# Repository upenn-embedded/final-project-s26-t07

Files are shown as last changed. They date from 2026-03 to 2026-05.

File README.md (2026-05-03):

# RoboBartender

**Team Number:** 7

**Team Name:** Team 7

|  Team Member Name  | Email Address |
|---|---|
| Lori Brown | blor@seas |
| Amy Luo | amyluo@seas |
| Jeremy Chung | ddchung@seas |

**GitHub Repository URL:** https://github.com/upenn-embedded/final-project-s26-t07

**GitHub Pages Website URL:** https://upenn-embedded.github.io/final-project-s26-t07/

## Final Project Proposal

### 1. Abstract  
We are building an autonomous assembly-line mocktail mixer which allows users to select a drink option. We plan to use an OLED screen and buttons for drink selection and notifications. Solenoids and pumps used in conjunction with load cells for each bottle will dispense the liquid and notify the user if a bottle needs to be refilled. The cup (detected using a load cell) will move through a series of stages corresponding to each bottle.

### 2. Motivation  
Mocktail and tea prices have been going up in the past few years. It is no longer appealing to buy an 8 dollar peach oolong tea, for example, which is very easy to make. We propose an autonomous drink-maker to solve this problem and save ourselves money. We want a device that we can use at home with minimal maintenance and cost.

### 3. System Block Diagram
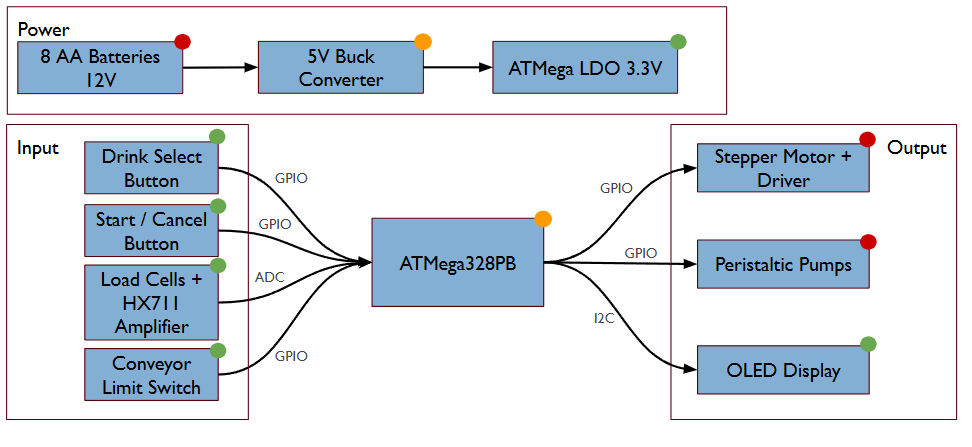
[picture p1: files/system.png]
   
### 4. Design Sketches  
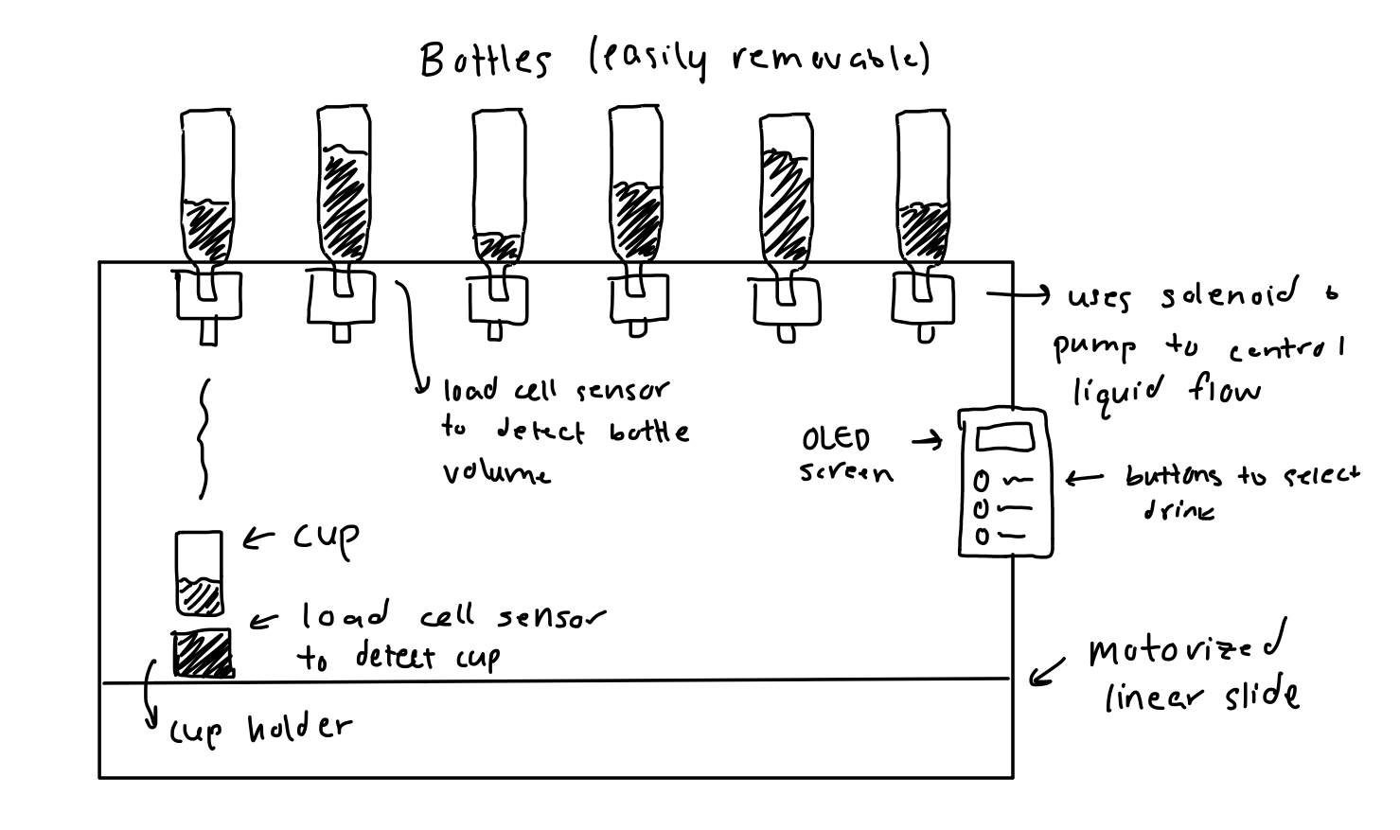
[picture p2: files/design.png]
  
The critical design features include the linear slide (to move the drink forward) and the solenoid-pump system to dispense the drink. We may need to 3D print a mount for each bottle. We can laser-cut a wooden display interface for drink selection and notification (to place the OLED and buttons in). We will also need to construct an outer frame for the device, which can be done using wood (since the bottles may be too heavy for cardboard).

### 5. Software Requirements Specification (SRS)

**5.1 Definitions, Abbreviations**

**5.2 Functionality**

| ID | Description |
| --- | --- |
| SRS-01 | The system shall measure bottle load cell values at least once every 1 second to determine whether sufficient liquid remains for dispensing. |
| SRS-02 | The system shall allow the user to select from available drink options using the button interface and display the selected option on the OLED screen within 1 second of input. |
| SRS-03 | The system shall verify that a cup is present at the starting position using the load cell before beginning the drink-making sequence. |
| SRS-04 | At each dispensing station, the system shall activate the corresponding solenoid and pump for the programmed dispense duration associated with the selected drink recipe. |
| SRS-05 | The system shall stop the drink-making process and display an error message if the cup is not detected during any stage of operation. |
| SRS-06 | After the selected drink has been completed, the system shall display a completion message to the user within 2 seconds. |

### 6. Hardware Requirements Specification (HRS)

**6.1 Definitions, Abbreviations**

**6.2 Functionality**

| ID | Description |
| --- | --- |
| HRS-01 | An OLED display shall be used to present drink options, status updates, and refill notifications to the user. The display shall have a minimum resolution of 128 × 64 pixels. |
| HRS-02 |A linear motion mechanism shall be used to move the cup between dispensing stations. The mechanism shall provide enough travel distance to position the cup beneath each ingredient outlet. |
| HRS-03 | A motor shall be used to drive the linear slide and shall provide sufficient torque to move a filled cup reliably through all dispensing stages. |
| HRS-04 | A solenoid valve and pump assembly shall be used for each ingredient bottle to control liquid dispensing. |
| HRS-05 |The outer frame shall be constructed from a rigid material capable of supporting the bottles, pumps, and motion system during operation. |

### 7. Bill of Materials (BOM)
[BOM](https://docs.google.com/spreadsheets/d/1Mw4CX4s19iIcAV7RWT3Ym583nlKp-pcjlx95vIQbqWI/edit?usp=sharing)    

The RoboBartender system will be centered around an ATmega328PB microcontroller, which serves as the primary controller for the device and runs bare-metal, register-level C firmware. The microcontroller manages all core system operations, including sensor acquisition, actuator control, and communication with the user interface. It was selected because it provides sufficient GPIO pins, multiple hardware timers for PWM generation, and communication peripherals such as SPI and I²C that enable reliable interaction with other components. To measure liquid quantities and detect ingredient availability, the system uses 5 kg strain-gauge load cells placed beneath the cup platform and each ingredient bottle. These sensors measure weight changes, allowing the system to detect cup presence, monitor how much liquid has been dispensed, and determine when bottles are empty. Because load cells output very small millivolt-level signals, HX711 load cell amplifier modules are used to amplify and digitize the signals so they can be read accurately by the microcontroller.

To dispense ingredients, the system uses 12 V peristaltic pumps, which allow controlled liquid flow while keeping the liquid isolated from mechanical components to maintain cleanliness. These pumps are driven using N-channel logic-level MOSFETs, which act as electronic switches so the microcontroller can control higher-current loads safely. A servo motor moves the cup platform between ingredient stations, and its position is controlled using PWM signals generated by the ATmega328PB’s hardware timers. The system provides user interaction through an SSD1306 I²C OLED display and push-button inputs, allowing users to select drink recipes and receive system status messages such as "Place Cup" or "Refill Bottle." Power is supplied by a 12 V regulated power supply, which drives the pumps and other high-power components, while a buck converter steps the voltage down to 5 V for the microcontroller, sensors, and display. Additional passive components such as resistors, capacitors, and flyback diodes are included to stabilize the circuit, filter noise, and protect components from voltage spikes generated by inductive loads like pumps and motors.

### 8. Final Demo Goals
The device will be set on a flat surface for demonstration. A drink will be selected by an audience member, and the device will create the drink. We will show how the device reacts to a drink requiring an amount of liquid from an empty bottle. 

### 9. Sprint Planning

| Milestone  | Functionality Achieved | Distribution of Work |
| --- | --- | --- |
| Sprint #1  |  HRS-02-05 | All team members will work together to design the outer structure. Jeremy will manufacture it. Lori will design + construct the bottle-operating structure. Amy will design + construct the linear slide structure. |
| Sprint #2  |  SRS-03, SRS-04, SRS-06 | Lori + Amy will work on SRS-04, SRS-06. Jeremy will work on SRS-03. |
| MVP Demo | All other specifications | Amy and Jeremy work on error handling. Lori works on OLED screen and responsiveness. |
| Final Demo | Stretch features | All team members will work together on stretch features. |

**This is the end of the Project Proposal section. The remaining sections will be filled out based on the milestone schedule.**

## Sprint Review #1

### Last week's progress
Last week we finalized the BOM and ordered the parts necessary for our project. We also clarified the responsibilties for each of the team members. 

### Current state of project
We have finalized the electrical schematic and the setup for our power modulator and touchscreen LED. We are in the process of CAD-designing our turntable.   

### Next week's plan
Prototype mechanical design and setup software framework (GFX library, controls, etc.) and begin integration. 

## Sprint Review #2

### Last week's progress
We received a lot of our parts (but are still waiting on motors). We updated our schematics and CADs, and are assembling our parts.
### Current state of project
The parts that we have are integrated into the circuit. We are working on the GFX library.
### Next week's plan
Lasercut the structure, acquire bottles for testing, receive + integrate the rest of the parts.
## MVP Demo

### Show a system block diagram & explain the hardware implementation.
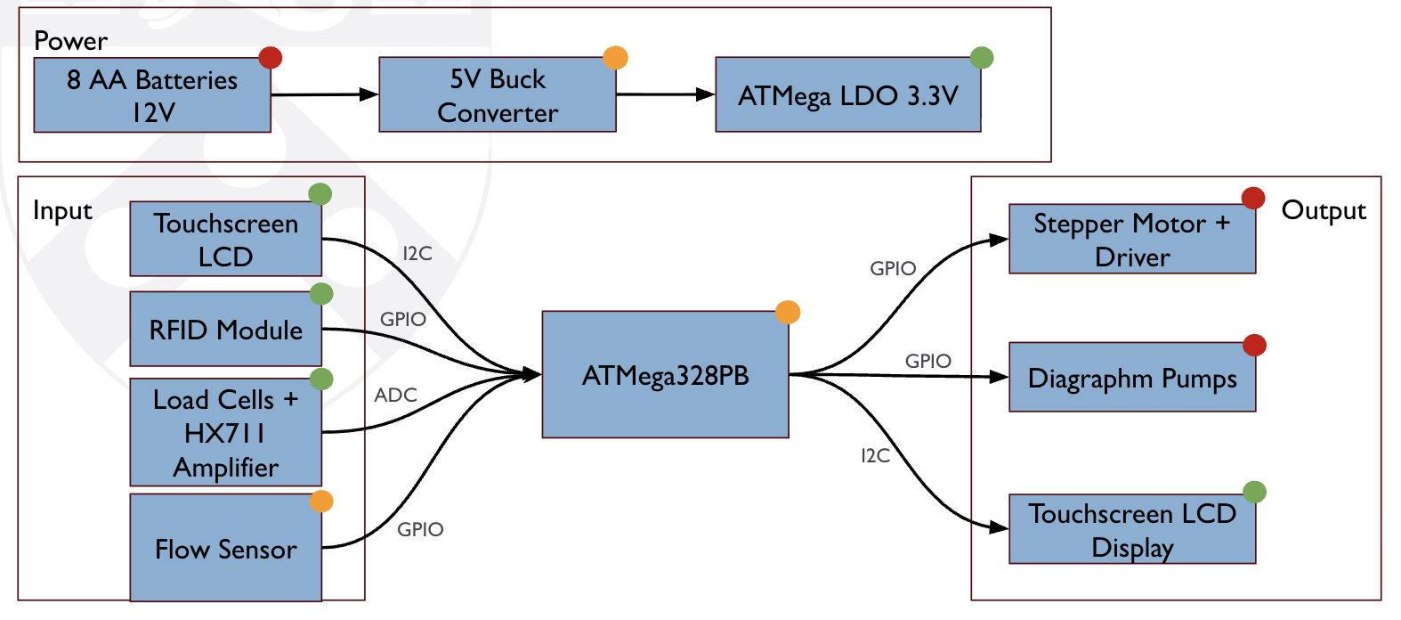
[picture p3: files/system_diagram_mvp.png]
  

The system consists of a 12V battery supplying a diaphragm pump directly and a 5V buck converter powering the ATmega328PB, touchscreen LCD (SPI), RFID module (SPI), and flow sensor (GPIO interrupt), with the pump driven through a MOSFET. The touchscreen LCD provides both user input and visual output, while the RFID module allows new recipes to be loaded, and the flow sensor provides real-time feedback to the microcontroller for precise volume control. Hardware implementation uses SPI for communication with the LCD and RFID (shared bus with separate chip select lines), a MOSFET for safe high-current pump control, and a closed-loop feedback system where the ATmega turns the pump on/off based on flow sensor pulses.

### Explain your firmware implementation, including application logic and critical drivers you've written.

The firmware is structured around a simple state machine that handles user interaction and dispensing logic, with states such as idle, selection, dispensing, and completion. The application reads touch input from the LCD and RFID data to determine the selected recipe, then activates the pump via a GPIO-controlled MOSFET while counting pulses from the flow sensor using an interrupt to precisely measure dispensed volume and stop at the target. Critical drivers include SPI communication for the touchscreen LCD and RFID module, an interrupt-based flow sensor driver for accurate pulse counting, and GPIO control for the pump and any motor drivers.

### Have you achieved some or all of your Software Requirements Specification (SRS)?
SRS-01: We have made slight adjustments to this specification, as instead of load cells, we are using fluid sensors to determine whehter sufficient liquid remains for dispensing. We have a working fluid sensor that can detect the volume of liquid passing through pulse calculations, and we plan on scaling this to 4 tube systems.

SRS-02/06: We are in the process of finishing up the Graphics library for the OLED screen, so we have not completed the drink selection interface yet. 

SRS-03/05: We are in the process of finishing our cup detection mechanism. 

SRS-04: We have a pump and fluid sensor system integrated together, and we plan on scaling to 4 tube systems. 

### Have you achieved some or all of your Hardware Requirements Specification (HRS)?
HRS-01: We are in the process of finishing up the Graphics library for the OLED screen, so we have not completed the display yet, however, we have integrated the hardware and circuity for the OLED screen into our system already. 

HRS-02: We are now using a rotational motion mechanism, a lazy Susan of sorts, to move the cup between dispensing stations. This is complete, apart from a couple screws and standoffs for stability. 

HRS-03: We have finished making the rotating platform and integrated the motor. 

HRS-04: We have finished the pump and fluid sensor assembly for 1 bottle, and we will scale to 4 this week. 

HRS-05: We have finished the outer frame. 

### What is the riskiest part remaining of your project?

The riskiest part remaining of our project is probably the controls in terms of dispensing and pump activation to the specific volume, as well as the I2C communication between the drink selection on the OLED screen to the dispenser. 

### How do you plan to de-risk this?

The priority is to divide the remaining software requirements into modular subsystems so that integration is simplified, and interdependencies are minimized. For instance, using a different clock for the motor and the fluid sensor.   

### What questions or help do you need from the teaching team?
We anticipate needing some guidance in terms of some of our stretch goals within the scope of the week we have left for the project, specifically the RFID integration, so if we foresee limitations, we plan on reaching out to Andrea to communicate them and ask about advice. 

## Final Report

Don't forget to make the GitHub pages public website!
If you’ve never made a GitHub pages website before, you can follow this webpage (though, substitute your final project repository for the GitHub username one in the quickstart guide):  [https://docs.github.com/en/pages/quickstart](https://docs.github.com/en/pages/quickstart)

### 1. Video

Link to video: 
[https://drive.google.com/drive/folders/1_ToFds5af0HQXXyNvEpmBM6VgKPU_a95?usp=sharing](https://drive.google.com/drive/folders/1_ToFds5af0HQXXyNvEpmBM6VgKPU_a95?usp=sharing)

### 2. Images

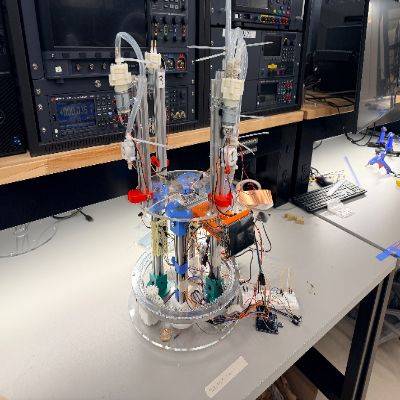
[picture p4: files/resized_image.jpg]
  

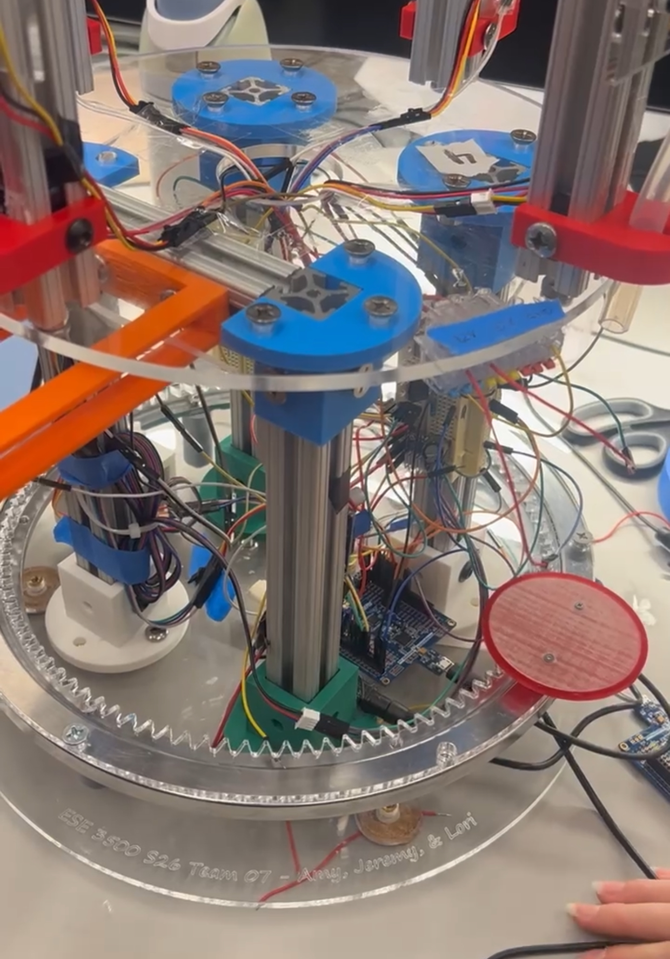
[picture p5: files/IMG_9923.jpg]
  

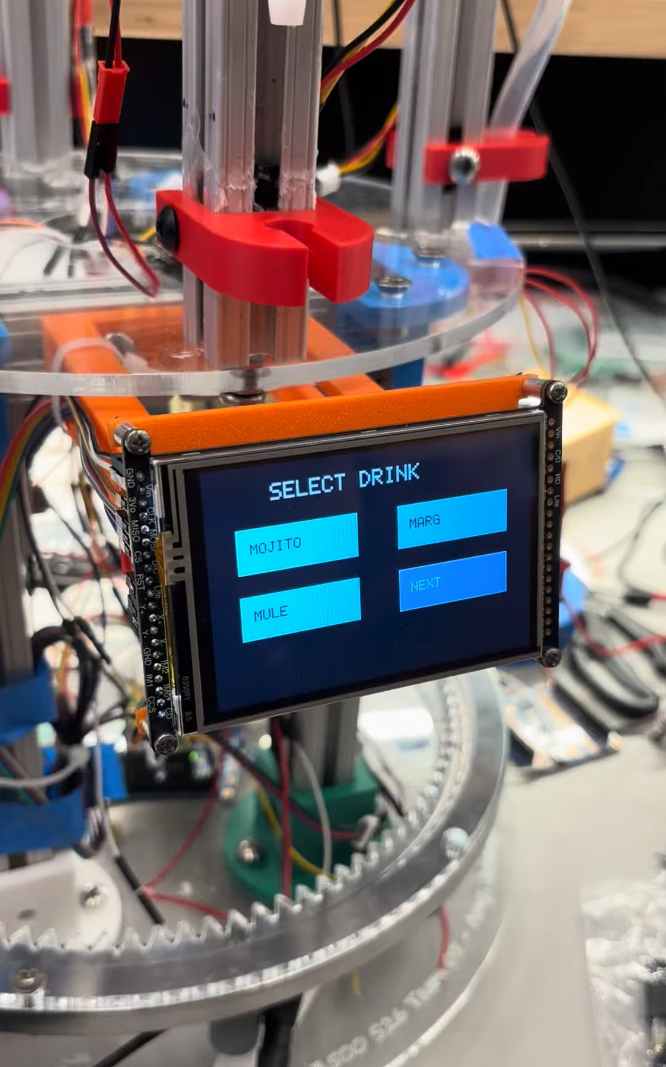
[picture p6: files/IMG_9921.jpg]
  

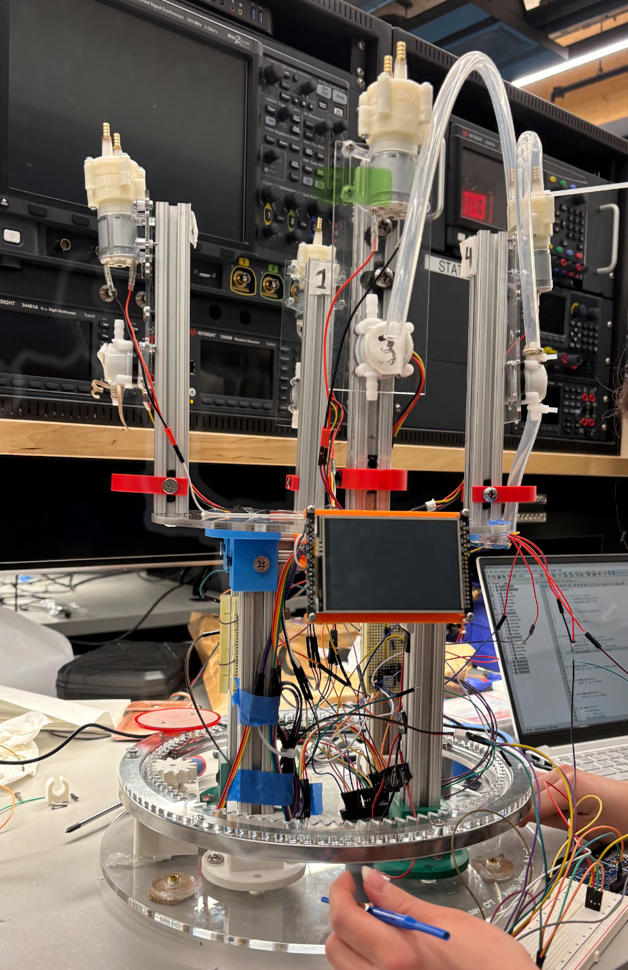
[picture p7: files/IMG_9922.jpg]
  

### 3. Results

#### 3.1 Software Requirements Specification (SRS) Results

Note: RFID recipe loading was removed from the final system design and is not included in the final validated requirements. Drink recipes are selected through the touchscreen interface using pre-programmed recipes stored in firmware.

| ID | Description | Validation Outcome |
|---|---|---|
| SRS-01 | The system shall measure flow sensor pulse data during dispensing to determine whether the programmed liquid volume has been delivered for each ingredient. | Confirmed, dispensed volume was validated using calibrated pulse counts and flow sensor output captures, though minor volumetric deviations were observed due to flow variability. |
| SRS-02 | The system shall allow the user to select from available drink options using the touchscreen interface and display the selected option on the LCD within 1 second of input. | Confirmed, touchscreen responsiveness was demonstrated in video and verified by timing user input to display update. |
| SRS-03 | The system shall verify that the cup is positioned at the correct dispensing station before beginning each dispense stage of the drink-making sequence. | Confirmed, turntable indexing and cup positioning were demonstrated in validation videos showing correct station alignment prior to dispensing. |
| SRS-04 | At each dispensing station, the system shall activate the corresponding pump for the programmed dispense volume associated with the selected drink recipe. | Partially achieved, recipe sequencing and multi-ingredient dispensing were demonstrated successfully, though occasional dispensing inaccuracies and timing inconsistencies introduced small recipe composition errors. |
| SRS-05 | The system shall stop the drink-making process and display an error message if a dispensing fault, positioning fault, or invalid operating condition is detected during any stage of operation. | Confirmed, fault handling was validated through induced error cases and demonstrated through LCD error messaging. |
| SRS-06 | After the selected drink has been completed, the system shall display a completion message to the user within 2 seconds. | Confirmed, completion message timing was verified through recorded demonstrations and LCD output. |

#### 3.2 Hardware Requirements Specification (HRS) Results

| ID | Description | Validation Outcome |
|---|---|---|
| HRS-01 | A touchscreen LCD shall be used to present drink options, status updates, and dispensing notifications to the user. The display shall support graphical output and touch input for recipe selection. | Confirmed, LCD graphics and touch functionality were demonstrated in system operation videos. |
| HRS-02 | A rotational motion mechanism shall be used to move the cup between dispensing stations. The mechanism shall provide sufficient angular positioning accuracy to align the cup beneath each ingredient outlet. | Confirmed, turntable positioning accuracy was validated through repeated dispensing alignment tests. |
| HRS-03 | A motor shall be used to drive the rotational platform and shall provide sufficient torque to move a filled cup reliably through all dispensing stages. | Partially achieved, the motor successfully drove the turntable during demonstrations, though intermittent driver overheating introduced reliability limitations during extended operation. |
| HRS-04 | A diaphragm pump and flow sensor assembly shall be used for each ingredient bottle to control and monitor liquid dispensing. | Confirmed, pump-flow sensor subsystem performance was validated through flow measurements and dispensing demonstrations, with minor calibration variability observed. |
| HRS-05 | The outer frame shall be constructed from a rigid material capable of supporting the bottles, pumps, tubing, electronics, and rotational motion system during operation. | Confirmed, mechanical frame integrity was demonstrated during integrated system testing with no structural failures observed. |
| HRS-06 | A regulated power and switching subsystem, including MOSFET-based pump drivers, shall be used to safely provide power and control for the microcontroller, sensors, display, and actuators. | Partially achieved, switching and power delivery functioned as intended, though motor driver thermal issues indicated areas for improvement in sustained power handling. |

### 4. Conclusion

This project taught us a great deal about embedded system design, particularly the challenge of integrating mechanical, electrical, and software subsystems into a functioning system. We learned that designing individual subsystems is often much easier than making them work together reliably, and that debugging integration issues can take significantly more time than expected. 

Several aspects of the project went well. One major success was our ability to adapt the specifications to better fit the realities of implementation, particularly pivoting from a linear slide architecture to a rotational dispensing platform, which simplified mechanical complexity while still satisfying the project goals. Our modular subsystem approach also worked well, allowing us to independently develop the touchscreen interface, pump-flow sensor control, and turntable mechanism before integrating them. We were also able to demonstrate a complete autonomous dispensing sequence, which was a major milestone.

We are particularly proud of building a fully functioning automated drink dispensing prototype from the ground up and getting multiple subsystems, including a touchscreen UI, flow-controlled pumps, turntable positioning, and embedded control firmware, to operate together. We are also proud of working through several design pivots rather than forcing the original concept when it was no longer optimal. 

From this experience, we learned that successful embedded system design is often less about the first design being correct and more about rapidly identifying constraints, adjusting requirements, and improving the design through iteration. We also gained valuable experience with debugging at both the hardware and firmware level. 

We definitely had to change our approach several times. Early on, we realized integration introduced issues that were not obvious when testing subsystems independently, which forced us to redesign portions of both the mechanics and controls. We changed both the motion subsystem and parts of the sensing approach, and we shifted focus from adding features to prioritizing robustness of the core functionality.

In hindsight, some things could have been done differently. More time spent on subsystem interface planning and early integration testing would have likely reduced late-stage debugging. We also could have prioritized power architecture and driver thermal considerations much earlier, since these became significant bottlenecks later in the project. More extensive calibration testing earlier in development would also have improved dispensing accuracy.

We did encounter obstacles we did not anticipate, especially around power management, which took significantly longer than expected. Managing multiple loads, protecting switching circuits, handling motor driver overheating, and ensuring stable operation under varying loads turned out to be much more challenging than initially assumed. Integration issues between mechanical motion and dispensing control also created challenges we had not fully predicted.

A potential next step for this project would be improving calibration and dispensing accuracy so recipes can be reproduced more consistently. Additional work could include closed-loop control improvements, more robust motor driving hardware, and expanding the recipe system through RFID or another dynamic recipe loading method. Beyond that, scaling to a more polished and reliable consumer-facing prototype with improved mechanical packaging and expanded drink customization would be an exciting continuation of the project.

## References

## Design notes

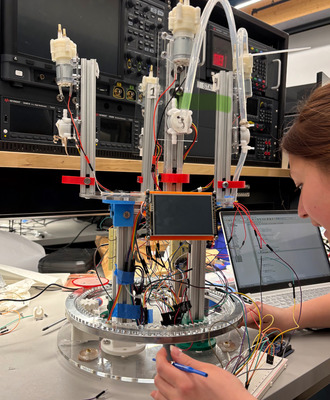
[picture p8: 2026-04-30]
files/small.jpg

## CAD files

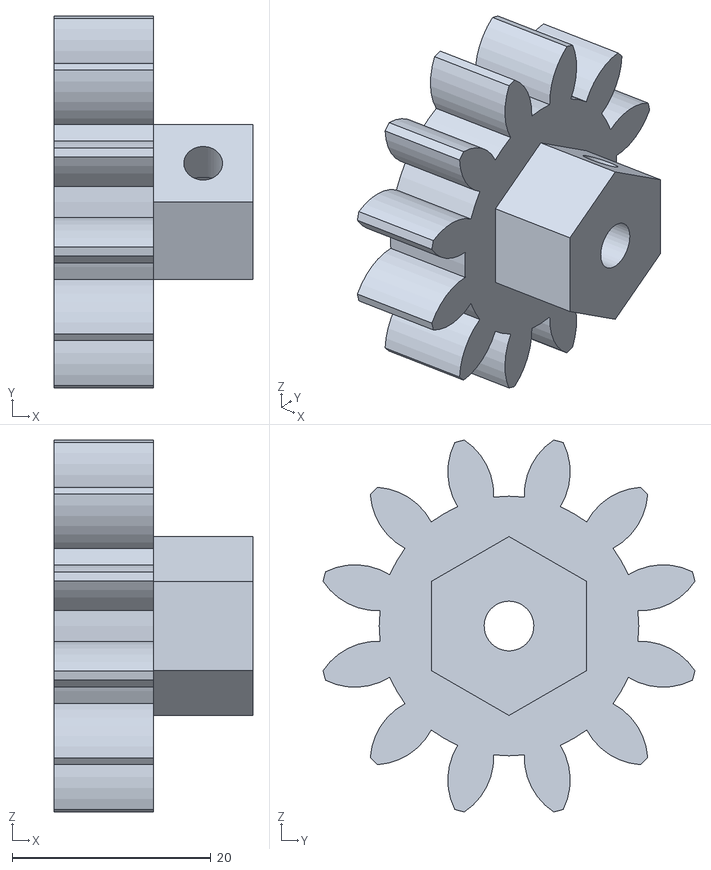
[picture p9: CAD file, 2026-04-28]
CAD Files/3d print/shaft_gear.STL
20.0 x 37.4 x 37.4

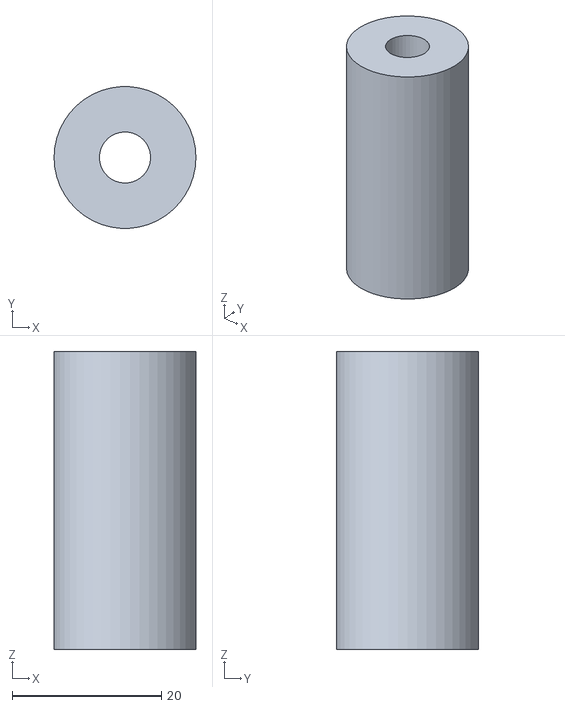
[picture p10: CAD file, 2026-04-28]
CAD Files/3d print/standoff_40mm.STL
19.1 x 19.0 x 40.0

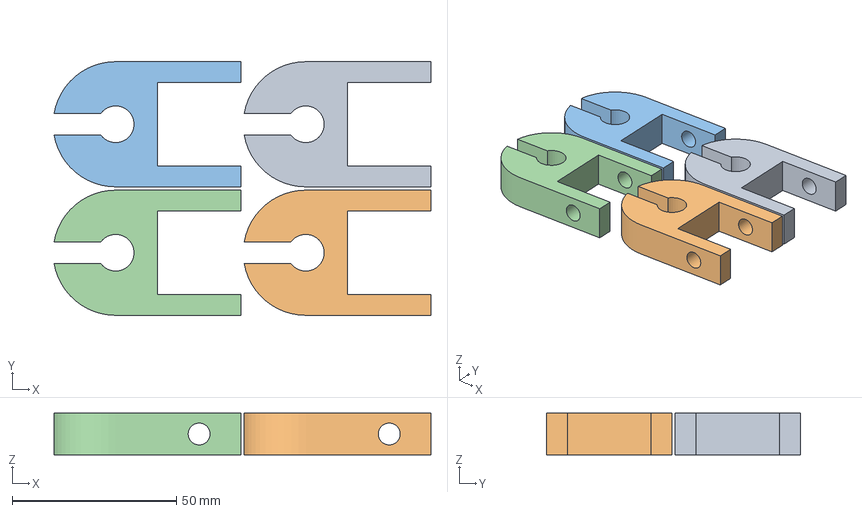
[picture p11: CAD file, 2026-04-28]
CAD Files/3d print/tube mount.3mf
114.7 x 77.2 x 12.7 mm
tube mount.STL x 4

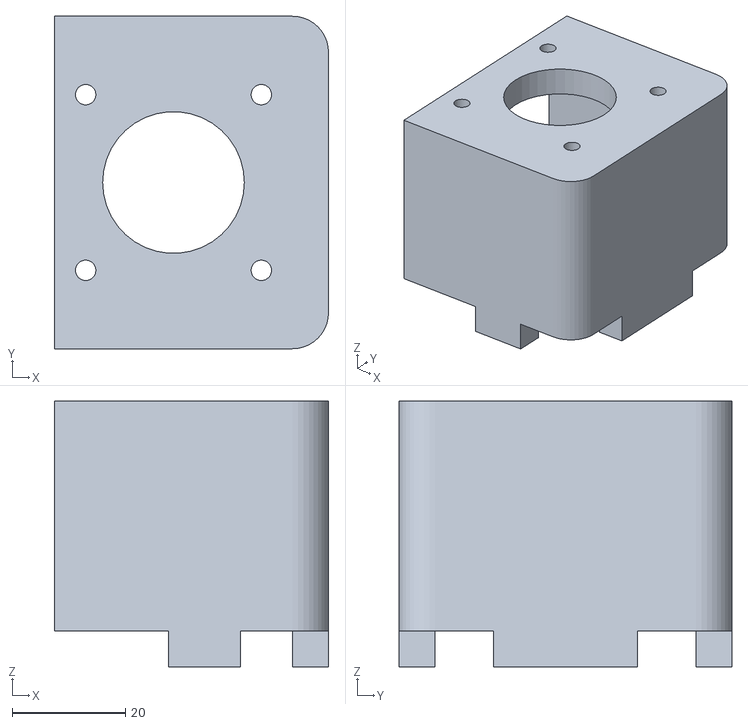
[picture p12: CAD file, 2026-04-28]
CAD Files/3d print/stepper motor mount.STL
48.3 x 58.7 x 46.9

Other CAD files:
CAD Files/3d print/lcd stand.gcode.3mf

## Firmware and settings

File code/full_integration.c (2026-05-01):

#define F_CPU 16000000UL

#include <avr/io.h>
#include <util/delay.h>
#include <avr/interrupt.h>
#include <stdio.h>
#include <stdlib.h>

#include "tft.h"
#include "touchscreen.h"
#include "ui.h"
#include "recipe.h"

// Motor
#define TURNTABLE_MOTOR_STEP   PD5
#define TURNTABLE_MOTOR_DIR    PD4
#define TURNTABLE_MOTOR_SLEEP  PD3

// Pumps
#define PUMP2                  PB0
#define PUMP3                  PD2

// Flow sensors
#define FLOW2                  PD7
#define FLOW3                  PD6

// Hall sensor moved off touchscreen pins
#define HALL_CHANNEL           4   // PC4 / ADC4
#define HALL_THRESHOLD         100

#define NUM_PUMPS              4
#define STEPS_PER_PUMP         417
#define ML_PER_PULSE           0.66

int current_position = 0;

volatile uint32_t flow_pulses_2 = 0;
volatile uint32_t flow_pulses_3 = 0;

uint16_t adc_read_main(uint8_t channel) {
    ADMUX = (1 << REFS0) | (channel & 0x0F);
    ADCSRA |= (1 << ADSC);
    while (ADCSRA & (1 << ADSC));
    return ADC;
}

ISR(PCINT2_vect) {
    static uint8_t last_flow2 = 1;
    static uint8_t last_flow3 = 1;

    uint8_t current_flow2 = (PIND & (1 << FLOW2)) ? 1 : 0;
    uint8_t current_flow3 = (PIND & (1 << FLOW3)) ? 1 : 0;

    if (last_flow2 == 1 && current_flow2 == 0) flow_pulses_2++;
    if (last_flow3 == 1 && current_flow3 == 0) flow_pulses_3++;

    last_flow2 = current_flow2;
    last_flow3 = current_flow3;
}

void bartender_init(void) {
    DDRD |= (1 << TURNTABLE_MOTOR_STEP) |
            (1 << TURNTABLE_MOTOR_DIR) |
            (1 << TURNTABLE_MOTOR_SLEEP) |
            (1 << PUMP3);

    DDRB |= (1 << PUMP2);

    DDRD &= ~((1 << FLOW2) | (1 << FLOW3));
    PORTD |= (1 << FLOW2) | (1 << FLOW3);

    DDRC &= ~(1 << PC4);
    PORTC |= (1 << PC4);

    PORTD |= (1 << TURNTABLE_MOTOR_SLEEP);
    PORTD |= (1 << TURNTABLE_MOTOR_DIR);
    PORTD &= ~(1 << TURNTABLE_MOTOR_STEP);

    PORTB &= ~(1 << PUMP2);
    PORTD &= ~(1 << PUMP3);

    PCICR |= (1 << PCIE2);
    PCMSK2 |= (1 << PCINT22) | (1 << PCINT23);

    sei();
}

void set_direction_clockwise(void) {
    PORTD |= (1 << TURNTABLE_MOTOR_DIR);
}

void set_direction_counterclockwise(void) {
    PORTD &= ~(1 << TURNTABLE_MOTOR_DIR);
}

void step_motor(void) {
    PORTD |= (1 << TURNTABLE_MOTOR_STEP);
    _delay_us(1900);
    PORTD &= ~(1 << TURNTABLE_MOTOR_STEP);
    _delay_us(1900);
}

void move_steps(int steps) {
    if (steps >= 0) {
        set_direction_clockwise();
    } else {
        set_direction_counterclockwise();
        steps = -steps;
    }

    for (int i = 0; i < steps; i++) {
        step_motor();
    }
}

void home_turntable(void) {
    set_direction_clockwise();

    while (1) {
        uint16_t hall_value = adc_read_main(HALL_CHANNEL);

        if (hall_value < HALL_THRESHOLD) {
            current_position = 0;
            break;
        }

        step_motor();
        _delay_ms(5);
    }
}

void move_to_pump(int pump_number) {
    int target_position = pump_number - 1;
    int step_difference = target_position - current_position;

    if (step_difference > NUM_PUMPS / 2) {
        step_difference -= NUM_PUMPS;
    } else if (step_difference < -NUM_PUMPS / 2) {
        step_difference += NUM_PUMPS;
    }

    move_steps(step_difference * STEPS_PER_PUMP);
    current_position = target_position;
}

void pump_on(int pump_number) {
    if (pump_number == 2) {
        PORTB |= (1 << PUMP2);
    } else if (pump_number == 3) {
        PORTD |= (1 << PUMP3);
    }
}

void pump_off(int pump_number) {
    if (pump_number == 2) {
        PORTB &= ~(1 << PUMP2);
    } else if (pump_number == 3) {
        PORTD &= ~(1 << PUMP3);
    }
}

void dispense_ml(int pump_number, float amount_ml) {
    uint32_t target_pulses = (uint32_t)(amount_ml / ML_PER_PULSE);

    if (pump_number == 2) {
        flow_pulses_2 = 0;
    } else if (pump_number == 3) {
        flow_pulses_3 = 0;
    } else {
        return;
    }

    pump_on(pump_number);

    if (pump_number == 2) {
        while (flow_pulses_2 < target_pulses) {
        }
    } else if (pump_number == 3) {
        while (flow_pulses_3 < target_pulses) {
        }
    }

    pump_off(pump_number);
}

void make_shirley_temple(void) {
    move_to_pump(2);
    dispense_ml(2, 100);

    _delay_ms(500);

    move_to_pump(3);
    dispense_ml(3, 200);
}

int main(void) {
    spi_init();
    tft_init();
    adc_init();

    bartender_init();

    ui_draw_homing();
    _delay_ms(200);

    home_turntable();
    
    _delay_ms(1000);
    
    move_to_pump(3);
    

    ui_set_drink_names("SHIRLEY", "WATER", "MILK");
    ui_init();
    
    while (1) {
        ui_update();

        if (ui_start_requested()) {
            ui_clear_start_request();
            ui_draw_dispense();

            if (ui_get_selected_drink() == 1) {
                make_shirley_temple();
            }

            _delay_ms(1000);
            ui_init();
        }

    _delay_ms(200);
    }
    
    
}

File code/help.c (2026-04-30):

#define F_CPU 8000000UL		/* Define CPU Frequency 8MHz */
#include <avr/io.h>
#include <util/delay.h>
#include <avr/interrupt.h>
#include <stdio.h>
#include "uart.h"

#define TURNTABLE_MOTOR_STEP   PD5
#define TURNTABLE_MOTOR_DIR    PD4
#define TURNTABLE_MOTOR_SLEEP  PD2

#define PUMP1                  PD3
#define PUMP2                  PD7
#define PUMP3                  PC4
#define PUMP4                  PC5

#define FLOW_SENSOR1           PD6
#define FLOW_SENSOR2           PB4
#define FLOW_SENSOR3           PE0
#define FLOW_SENSOR4           PE1
#define HALL_EFFECT_SENSOR     PE2


#define FLOW_RATE              0.66 // mL / # ticks

// TODO: Currently only tracks FLOW_SENSOR1
volatile uint32_t pulse_count = 0;
volatile uint32_t pulse_count2 = 0;
volatile uint32_t pulse_count3 = 0;
volatile uint32_t pulse_count4 = 0;

ISR(PCINT2_vect) {
    static uint8_t last_state = 0;
    uint8_t current_state = (PIND & (1 << FLOW_SENSOR1)) ? 1 : 0;

    if (current_state && !last_state) {
        pulse_count++;
    }

    last_state = current_state;
}

ISR(PCINT0_vect) {
    static uint8_t last_state2 = 0;
    uint8_t current_state2 = (PINB & (1 << FLOW_SENSOR2)) ? 1 : 0;

    if (current_state2 && !last_state2) {
        pulse_count2++;
    }

    last_state2 = current_state2;
}

ISR(PCINT3_vect) {
    static uint8_t last_state3 = 0;
    static uint8_t last_state4 = 0;

    uint8_t current_state3 = (PINE & (1 << FLOW_SENSOR3)) ? 1 : 0;
    uint8_t current_state4 = (PINE & (1 << FLOW_SENSOR4)) ? 1 : 0;

    if (current_state3 && !last_state3) {
        pulse_count3++;
    }

    if (current_state4 && !last_state4) {
        pulse_count4++;
    }

    last_state3 = current_state3;
    last_state4 = current_state4;
}

void flow_sensor_init1() {
    DDRD &= ~(1 << FLOW_SENSOR1);

    // enable pull-up on PD1
    PORTD |= (1 << FLOW_SENSOR1);

    PCICR |= (1 << PCIE2);
    PCMSK2 |= (1 << PCINT22);
}

void flow_sensor_init2() { // PB4
    DDRB &= ~(1 << FLOW_SENSOR2);
    PORTB |= (1 << FLOW_SENSOR2);

    PCICR |= (1 << PCIE0);          // Enable Port B interrupts
    PCMSK0 |= (1 << PCINT4);        // PB4
}

void flow_sensor_init3(void) {
    DDRE &= ~(1 << FLOW_SENSOR3);
    PORTE |= (1 << FLOW_SENSOR3);

    PCICR |= (1 << PCIE3);
    PCMSK3 |= (1 << PCINT24);
}

void flow_sensor_init4(void) {
    DDRE &= ~(1 << FLOW_SENSOR4);
    PORTE |= (1 << FLOW_SENSOR4);

    PCICR |= (1 << PCIE3);
    PCMSK3 |= (1 << PCINT25);
}


void pump_init(int pump) {
    // set to output direction
    DDRD |= (1 << pump);
}

void initialize() {
    // set pin direction to output
    DDRD |= (1 << TURNTABLE_MOTOR_STEP);
    DDRD |= (1 << TURNTABLE_MOTOR_DIR);
    DDRD |= (1 << TURNTABLE_MOTOR_SLEEP);
    pump_init(PUMP1);
    pump_init(PUMP2);
    pump_init(PUMP3);
    pump_init(PUMP4);

    // set motor dir
    PORTD |= (1 << TURNTABLE_MOTOR_DIR);

    // set sleep to 0
    PORTD &= (1 << TURNTABLE_MOTOR_SLEEP);

    flow_sensor_init1();
    flow_sensor_init2();
    flow_sensor_init3();
    flow_sensor_init4();

    sei();
}

void run_motor(int iters) {
    PORTD |= (1 << TURNTABLE_MOTOR_SLEEP);
    for (int i = 0; i < iters; i++) {
        PORTD |= (1 << TURNTABLE_MOTOR_STEP);
        _delay_us(20); // short pulse
        PORTD &= ~(1 << TURNTABLE_MOTOR_STEP);
        _delay_ms(5); // faster stepping
    }
    PORTD &= ~(1 << TURNTABLE_MOTOR_SLEEP);
}

void pump_on(int pump) {
    PORTD |= (1 << pump);
}

void pump_off(int pump) {
    PORTD &= ~(1 << pump);
}

// run pump for mL amt of mL

void run_pump(double mL, int pump) {
    uint32_t count;
    pump_on(pump);
    printf("PUMP ON\n");
    uint32_t target_pulses = (uint32_t) (mL / FLOW_RATE);


    cli();
    count = pulse_count;
    sei();

    while (1) {
        cli();
        count = pulse_count;
        sei();
        printf("Pulse count: %lu\r\n", (unsigned long) count);

        if (count >= target_pulses) {
            break;
        }
    }
    pump_off(pump);
    printf("PUMP OFF\n");
}

int main(void) {
    initialize();
    uart_init();
    run_motor(2000);
//    run_pump(FLOW_RATE * 600, PUMP1);

//    while (1) {
//        uint32_t count;
//
//        cli();
//        count = pulse_count;
//        sei();
//
//        printf("Pulse count: %lu\r\n", (unsigned long)count);
//        _delay_ms(500);
//
//    }
}

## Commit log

2026-04-22 motor + pump almmost working
2026-04-22 MOTOR WORKSSS
2026-04-28 added all cad files
    [lcd stand.gcode.3mf, shaft_gear.STL, standoff_40mm.STL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]
2026-04-30 Add motor control and pump definitions
